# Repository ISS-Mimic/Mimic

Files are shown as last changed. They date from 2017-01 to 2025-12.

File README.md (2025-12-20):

<!-- =========================================================
  ISS Mimic  •  Re-create the ISS attitude & telemetry in real-time
  ========================================================= -->

<p align="center">
  ISS Mimic logo
</p>

<p align="center">
  
  
  
  
</p>

> **ISS Mimic** is an open-source mash-up of hardware + software that **mirrors the International Space Station’s solar-array and radiator motion** in real time.  
> Runs on Raspberry Pi • 12 motors drive a 3-D printed ISS • Live telemetry visualizer

---

ISS Mimic is a 3D printed model of the International Space Station that connects to the actual live data from the real ISS to control a model that rotates solar panels and radiators to match the real one in real time. The goal of this project is to connect people with the ISS. There are three different mimic models: Mimic, Mini Mimic, and Edu Mimic. These models are designed for teachers, students, museums, hobbyists, and anyone who wants to learn more about the ISS. 

Join the discussion, help out, ask for help, chat about the ISS here: [Mimic Discord](https://discord.gg/zPKyE6hBSe)



<details>
<summary>Table of Contents</summary>

- [Features](#features)
- [Quick Start (Raspberry Pi)](#quick-start-raspberry-pi)
- [Project Architecture](#project-architecture)
- [Build Your Own Model](#build-your-own-model)
- [Screenshots](#screenshots)
- [Contributing](#contributing)
- [Roadmap](#roadmap)
- [License](#license)
</details>

---

### Features
- **Live telemetry pull** from NASA’s Lightstreamer endpoint – no scraping needed  
- **Interactive dashboards** (more capable than the original ISSLive site)  
- **Real-time kinematics**: 12-axis motion matches α- and β-gimbal joint angles  
- **Modular design**: Separate Pi (telemetry & UI) ↔ Arduino (motor control)  
- **Low- / High-fidelity STLs** you can print today  

### Quick Start (Raspberry Pi)
```bash
# 1. Clone & install deps
  git clone --depth 1 https://github.com/ISS-Mimic/Mimic.git/ 
  cd ~/Mimic
  python setup.py

# 2. Run the Mimic GUI dashboard
  cd ~/Mimic/Pi/
  python GUI.py
```
Full software guide: [Wiki » Software Setup Instructions](https://github.com/ISS-Mimic/Mimic/wiki/Build-Instruction%3A-Mimic-Software-Setup-Instructions).

### Telemetry
Telemetry is data remotely collected from the ISS and transmitted to the ISS Mission Control Centers for monitoring the operational status of ISS systems. 

In 2011 some incredible JSC employees released a subset of the 100,000+ ISS telemetry items to the public under the ISSlive! project and an associated website.
Sadly, that website is no longer running, but they opened the door for dozens of projects to follow in their footsteps. 

NASA contracted the wonderful folks at [Lightstreamer](https://lightstreamer.com/) to provide this subset of ISS telemetry out to the public and that is the source of all the public telemetry projects today. 

We have made three telemetry pages to show off all of the public data (as well as our Pi application screens).

A filterable table here: https://iss-mimic.github.io/Mimic/ (and in Russian: https://iss-mimic.github.io/Mimic/index_ru.html)
and a great dashboard here: https://iss-mimic.github.io/Mimic/dashboard.html

### Project Architecture
```text
┌──────────┐              ┌──────────────┐                ┌──────────────┐                 ┌──────────┐
│ NASA LS  │────────────▶│ Raspberry Pi │───────────────▶│  Arduino(s)  │───────────────▶│  Motors  │
└──────────┘  telemetry   └──────────────┘  joint angles  └──────────────┘  motor commands └──────────┘
```
*Pi side* (Python + Kivy) shows telemetry dashboards and forwards joint targets.  
*Arduino side* (C++) drives stepper/servo motors in the 3-D-printed truss.

### Build Your Own Model
| Fidelity | STL pack | Status |
|---|---|---|
| Low | [`/3D_Printing`](3D_Printing) | ✔ Complete |
| High | `/3D_Printing/high_fidelity` | In progress – contributors welcome! |

Mechanical details, BOM, and wiring live in the **[Hardware Wiki section](https://github.com/ISS-Mimic/Mimic/wiki/Hardware)**.

### Screenshots
<p align="center">
  Mimic1
  Mimic2
  Mimic3
  <br>
  Mimic4
  Mimic5
  Mimic6
  <br>
  Mimic7
  Mimic8
  Mimic9
</p>

### Contributing
Start by opening an issue to suggest am improvement or bug or by chatting on **[Discord](https://discord.gg/zPKyE6hBSe)**.  
Coding guidelines:
1. Follow **PEP 8** and keep GUI layout in **`.kv` files** (Kivy best practice).  
2. Fix all our mistakes. 

Other help:
-Feel free to suggest ideas! Best place to talk is out discord, or feel free to publish an issue

### Roadmap
- [ ] Finish high-fidelity CAD & release STEP source
- [ ] Complete build guide
- [ ] Finish Kivy telemetry screens  

### License
This project is licensed under the MIT License – see [`LICENSE`](LICENSE) for details.

<details>
<summary>The code is ugly and awful but it works *mostly* (click to vent)</summary>

We’re hardware engineers moonlighting as coders. Expect caffeine-driven hacks and the occasional refactor fiasco. Contributions and constructive feedback are *super* welcome!
</details>

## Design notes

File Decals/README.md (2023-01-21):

# Vinyl cut Recommendation 

|  **Sub-Assembly / Module Name** | **STL Name & Link** | **Qty** | **Color** | **Comments** | **Approx  Time [h:mm]** | **_** | **_** |
| ---- | --- | --- | --- | --- | --- | --- | --- |
| Solar Array | [SAW_svg_working.svg ***](https://github.com/ISS-Mimic/Mimic/blob/main/Decals/SAWvinylFinal.svg) | 4 | Holographic Chrome Gold vinyl | [ To download .svg file, click on 'Raw' then 'right click' to save image.  Click here to open vinyl cut instructions.  Be sure to click the " **More Pages**" button in Github to see all instructions on using Cricut](https://github.com/ISS-Mimic/Mimic/blob/main/Decals/Vinyl_Cutting_Instructions_using_Cricut_.pdf) | 5:00 |  |  |
| Solar Array Back | [SAW_svg_working_BACK.svg ]() | 16 | Matte Metallic Champagne Gold vinyl |  | 0:10 |  |  |
| Solar Array Blue | [SAW_svg_working_BACK.svg ]() | 16 | Blue vinyl |  | 0:10 |  |  |
| IPA Roll Out Solar Arrays | [iROSA_SAWvinylFinal.svg ***](https://github.com/ISS-Mimic/Mimic/blob/main/Decals/iROSA_SAWvinylFinal.svg) | 2 | Holographic Chrome Gold vinyl |  | 2:00 |  |  |

*** Note: to download .svg file:
    >> copy all raw content
    >> paste into notepad
    >> save file with .svg extention ***

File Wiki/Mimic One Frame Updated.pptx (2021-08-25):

## Mimic One Frame Build Instruction (Example)

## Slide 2

FWD

2020 Vertical Supports (4)

Extruded 2040 Base

2020 Frame Supports (6)

Support Rods with Base (3)

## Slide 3

Step 1: Attach Frame Supports to 2040 Base (6 places)
2 small L-brackets each support, 2 Button Hex Screws each small L-bracket

Measurements are from centerline to centerline

2020 Frame Supports (6)

Frame Supports attached to 2040 Base by 2 small L-brackets using Button Hex Screws

Extruded 2040 Base

~610mm

~610mm

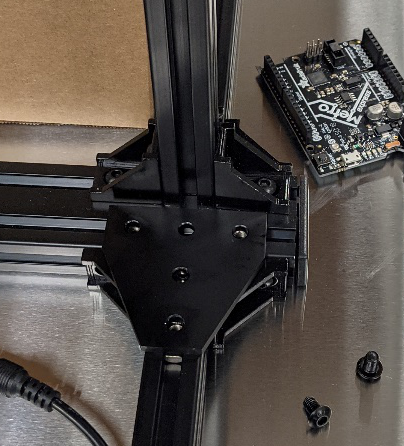
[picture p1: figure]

L-brackets

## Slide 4

Step 1a: Cut Rubber Strips for Frame Supports (6 places) and 2040 Base (both grooves)
Install Rubber Strips in the underside grooves of Frame Supports and 2040 Base.

The Rubber Strip provides friction with the table and to fill the space between the table and the Rubber Feet on the end of the Frame Supports.

2020 Frame Supports (6)

Extruded 2040 Base (both grooves)

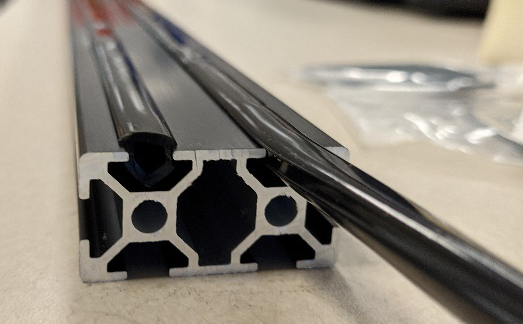
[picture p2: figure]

2040 Base shown upside down

Underside Groove

Rubber Strip

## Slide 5

Step 2: Install T-Plates on end Frame Supports in the rear groove of the 2040 (2 places)
1 T-plate per end Frame Support, 5 Button Hex Screws and T-nuts on each T-plate

2020 Frame Supports (6)

Frame Supports attached to 2040 Base by 2 small L-brackets and 1 T-plate using Button Hex Screws

Extruded 2040 Base

T-plate

L-brackets

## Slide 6

Step 3: Install T-Plates on center Frame Supports – one in forward groove, one in rear groove (2 places)
1 T-plate per center Frame Support, 5 Button Hex Screws and T-nuts on each T-plate

FWD

2020 Frame Supports (6)

Extruded 2040 Base

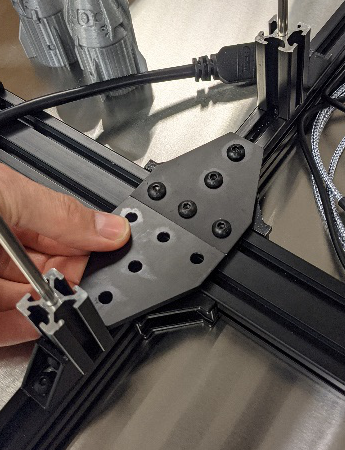
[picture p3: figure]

T-plates

Forward Groove in 2040

Rear Groove in 2040

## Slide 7

Vertical Supports (without T-plates) attached to forward groove with 2 small
L-brackets using
Button Hex screws

2020 Vertical Supports (4)

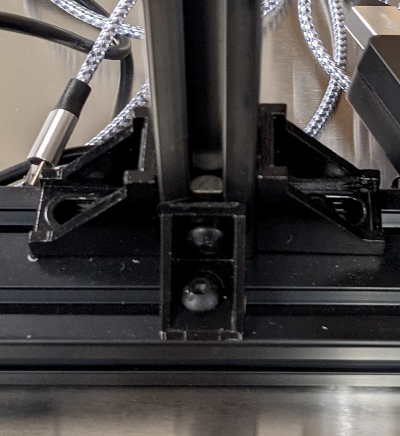
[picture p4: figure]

L-brackets

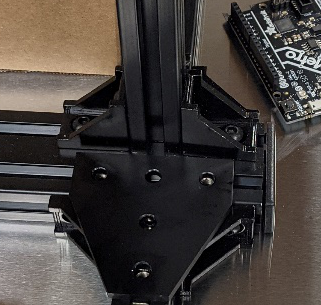
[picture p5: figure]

L-brackets

Vertical Supports attached to forward groove on 2040 Base by 2 small L-brackets using Button Hex Screws

Measurements are centerline to centerline.
Need to update: outside dimensions should be the same.

FWD

446mm

433mm

347mm

Extruded 2040 Base

Step 4: Attach Vertical Supports to forward groove in 2040 Base (4 places)
2 small L-brackets each support, 2 Button Hex Screws each small L-bracket

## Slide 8

Vertical Supports (without T-plates) attached to forward groove with 2 small
L-brackets and 1
L-bracket anchored in rear groove

2020 Vertical Supports (4)

Step 5: Add 1 large L-bracket anchored in rear groove in 2040 Base on center supports(2 places)
1 large L-bracket each support, 2 Button Hex Screws each small L-bracket

FWD

Extruded 2040 Base

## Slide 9

Step 6: Support Rod Bases on center Frame Supports (3 places)
1 large L-bracket per Support Rod Base, 2 Button Hex Screws each L-bracket

2020 Frame Supports (6)

160mm

243mm

Extruded 2040 Base

L-brackets

Vertical 2020 is flush
with end of the horizontal 2020

Support Rods with Base (3)

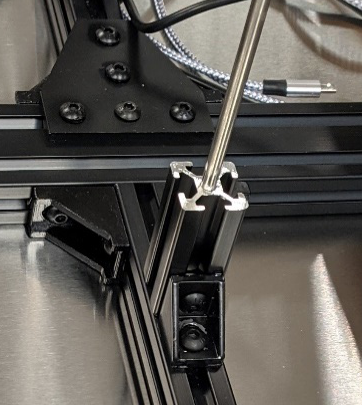
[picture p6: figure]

Support Rod Base attached to 2020 Frame Support by 1 large
L-bracket using Button Hex Screws

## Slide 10

Step 7: Install Rubber Feet on Support Rod Bases (3 places)
Rubber Feet finish off ends of extruded Support Rod Bases and provide additional support with rods

Note, a cut will need to be made or a small hole drilled to allow Support Rod to pass through – hole must be smaller than rod to provide friction for extra stability

2020 Frame Supports (6)

Extruded 2040 Base

Add new photo with rubber

Rubber Feet on Support Rod Base

Support Rods with Base (3)

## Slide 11

Step 8: Insert Support Rods in Support Rod Bases (3 places)
Support Rod will drop down into groove of Frame Support

2020 Frame Supports (6)

Extruded 2040 Base

Add new photo with rubber

Support Rod inserted through Rubber Feet into Support Rod Base

Support Rods with Base (3)

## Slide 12

Step 9: Install Rubber Feet on Frame Supports (6 places)
Rubber Feet finish off ends of Frame Supports and provide friction with table

2020 Frame Supports (6)

Extruded 2040 Base

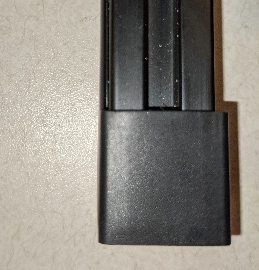
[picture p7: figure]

Support Rods with Base (3)

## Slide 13

Step 10: Install End Caps on 2040 Base ends (2 places)
End Caps finish off ends of 2040 Base

Extruded 2040 Base

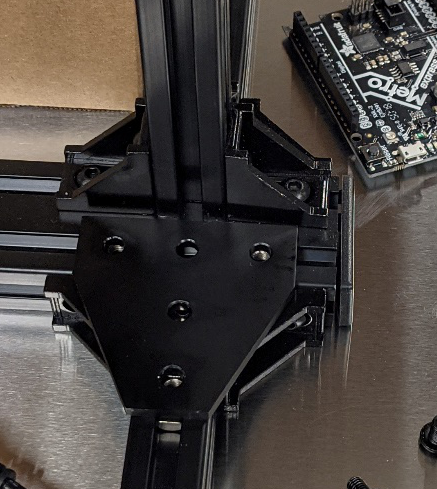
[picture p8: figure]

End Cap (2) inserted into end of 2040 Base

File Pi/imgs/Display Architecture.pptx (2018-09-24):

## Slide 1

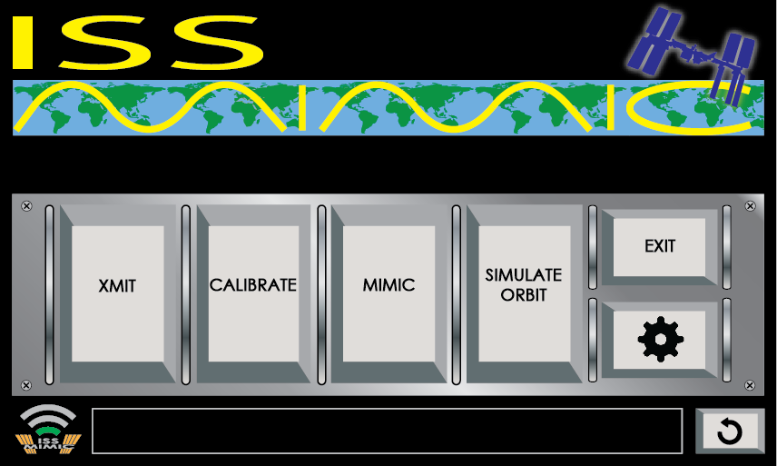
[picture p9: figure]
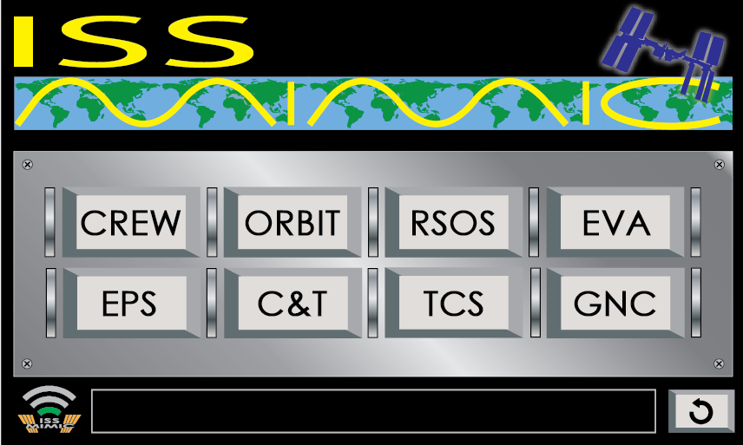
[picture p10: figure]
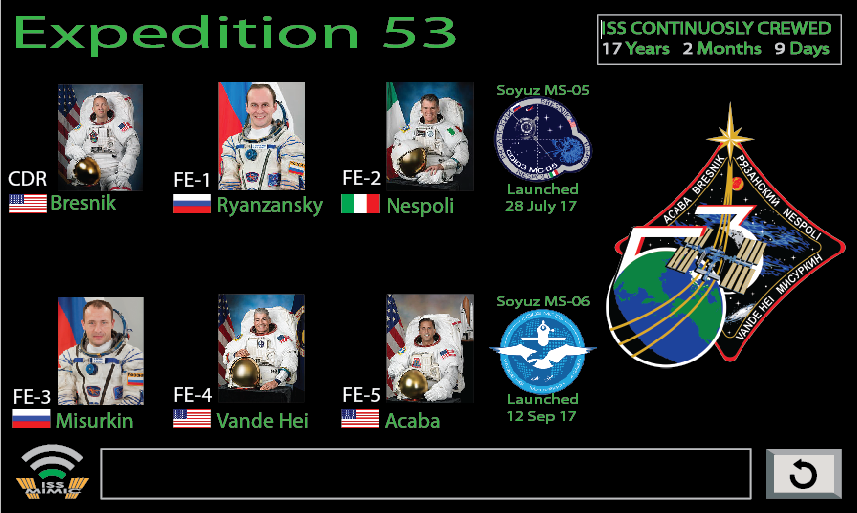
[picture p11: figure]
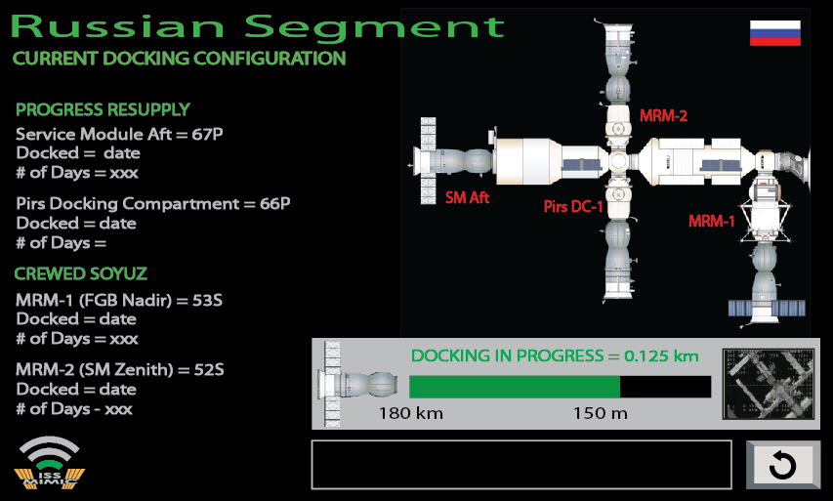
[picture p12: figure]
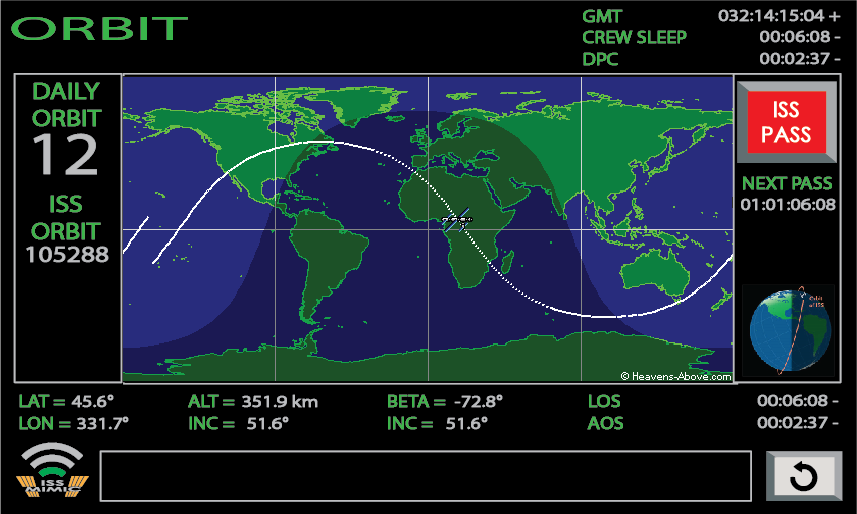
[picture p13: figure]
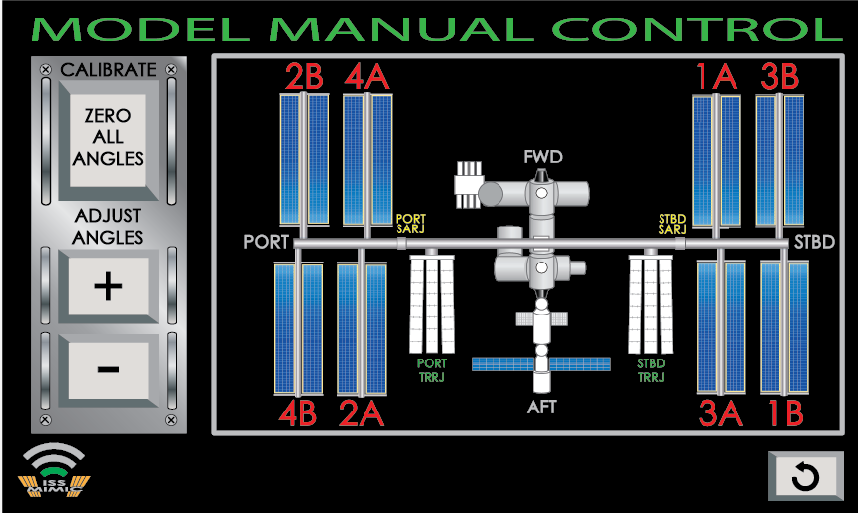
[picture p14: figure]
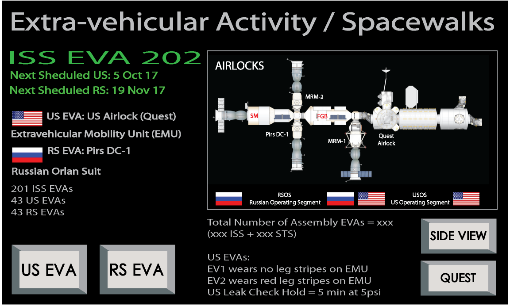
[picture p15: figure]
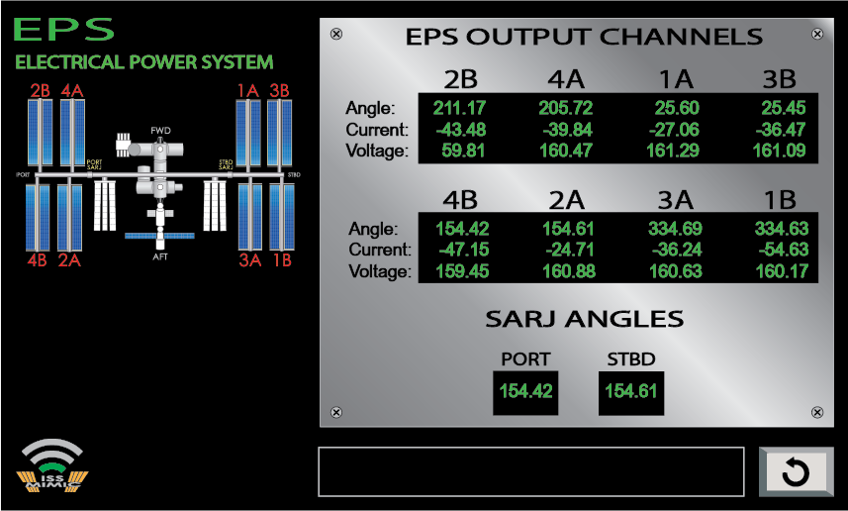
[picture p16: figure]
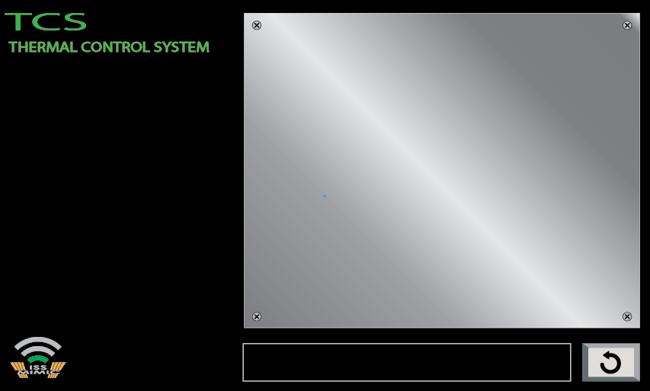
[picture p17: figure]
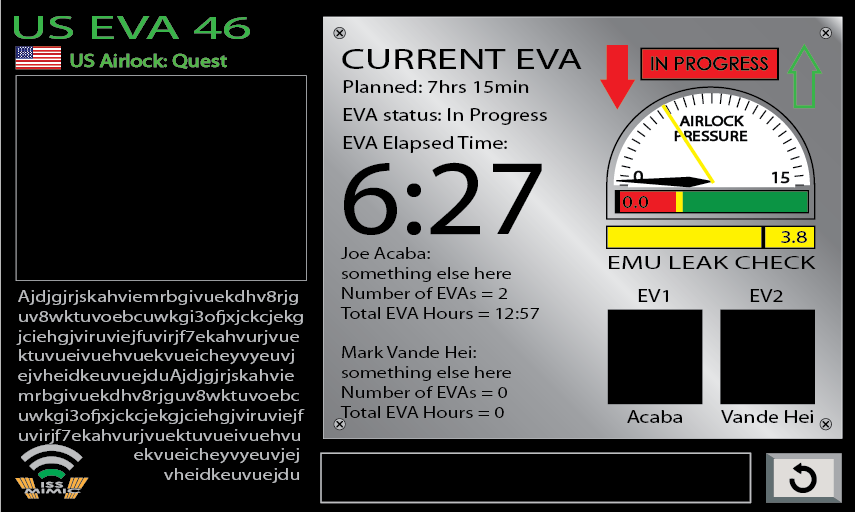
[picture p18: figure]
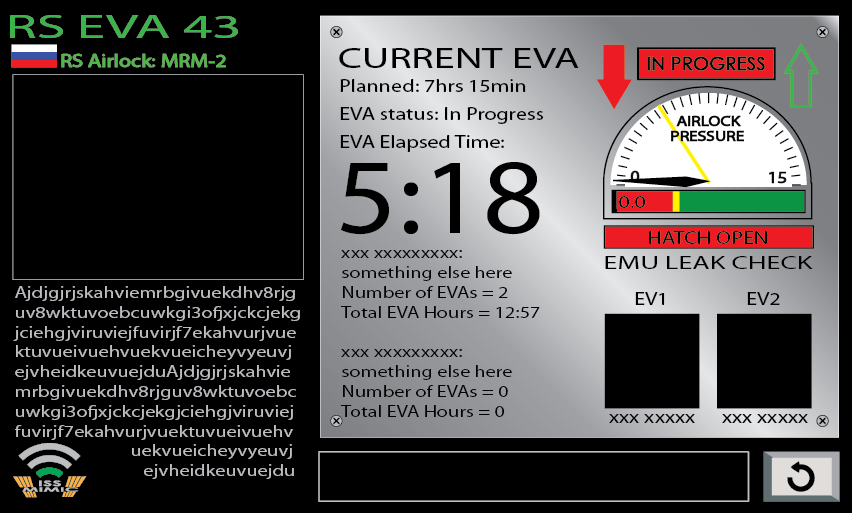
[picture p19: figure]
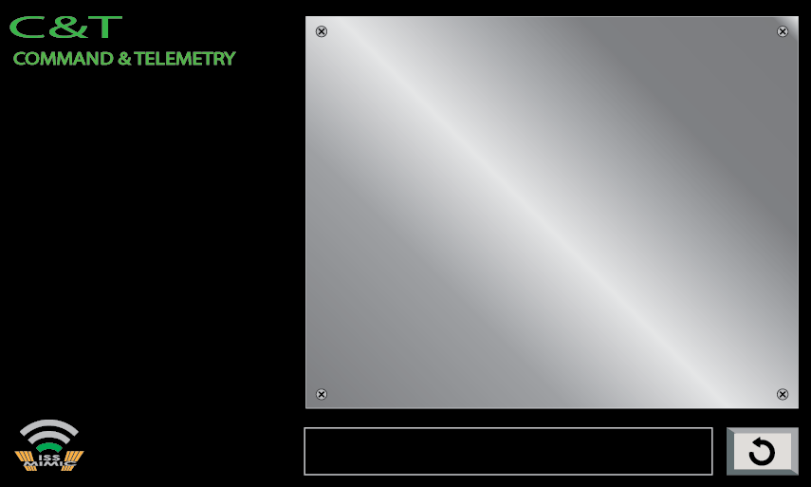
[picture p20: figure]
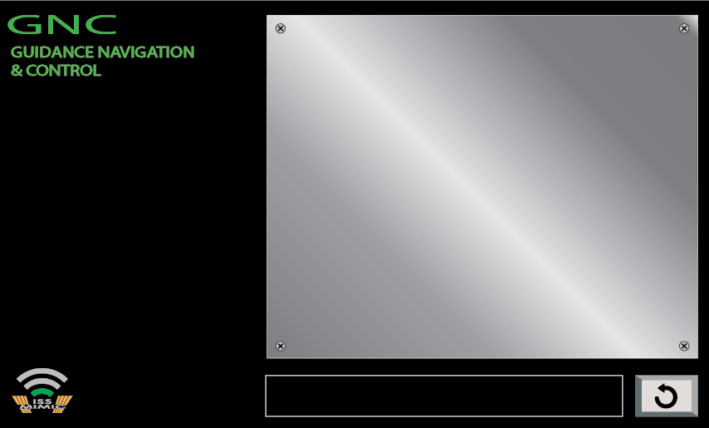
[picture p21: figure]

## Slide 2

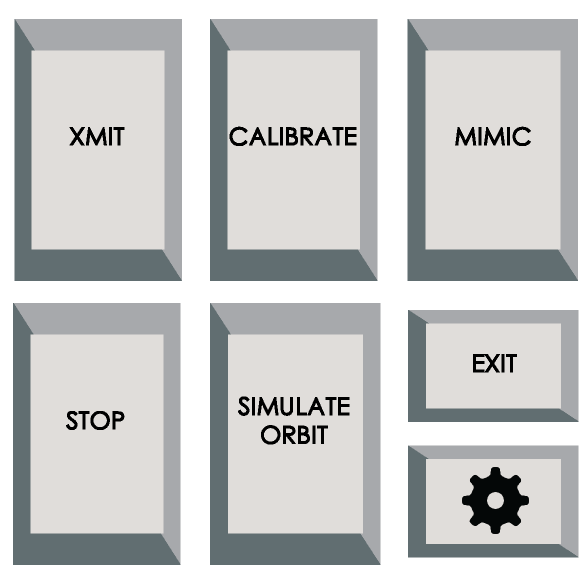
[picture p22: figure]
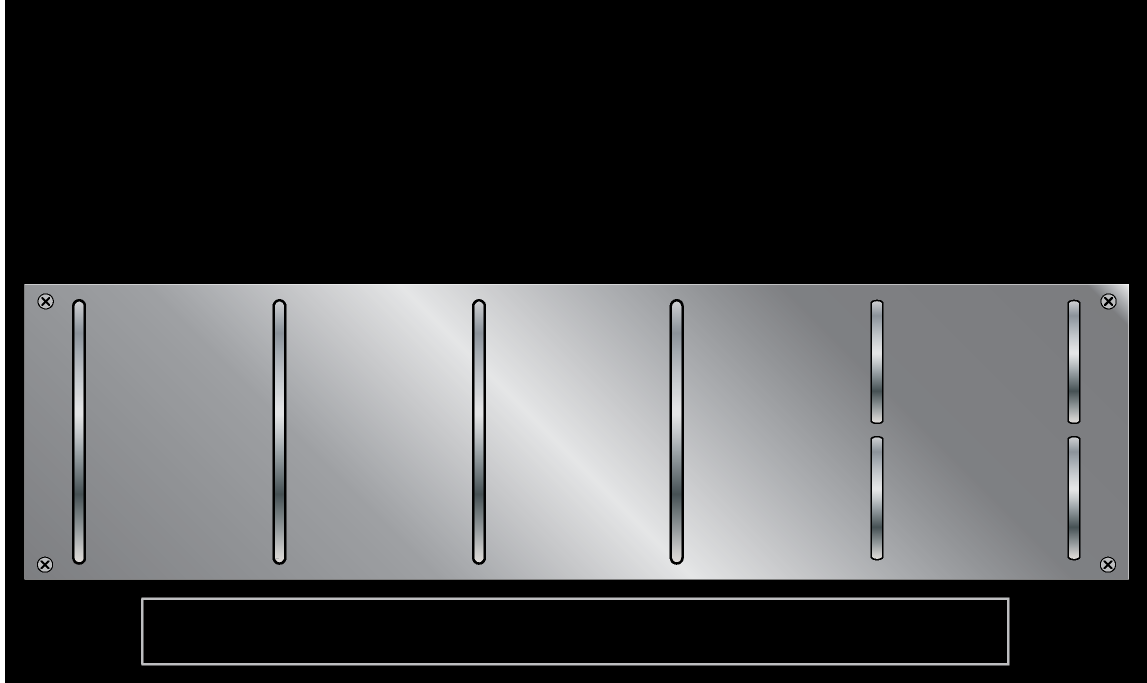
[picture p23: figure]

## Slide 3

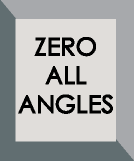
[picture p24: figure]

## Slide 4


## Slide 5


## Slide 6

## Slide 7

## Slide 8

View Buttons are static – choose from Side View or Quest View (don’t remember why I did that)


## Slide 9

Maybe if tweet is more than 220 characters, you truncate it or show 150 and spit out a link like it does on my phone

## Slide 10

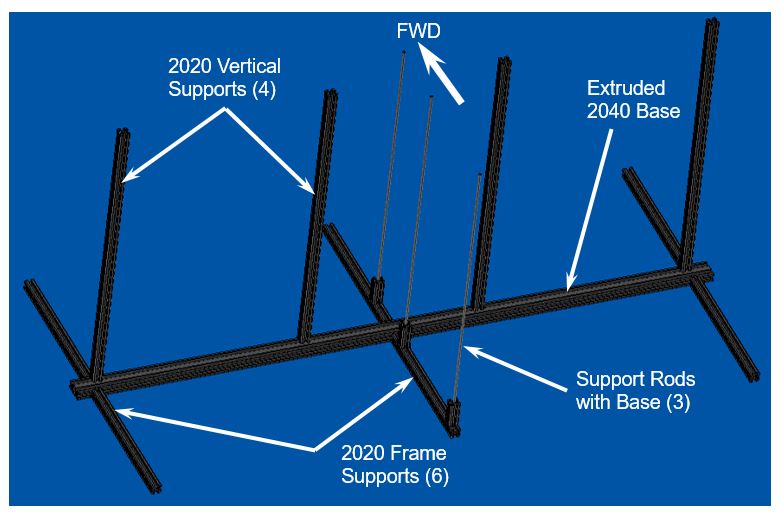
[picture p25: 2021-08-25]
Wiki/Images/FrameOverview.JPG

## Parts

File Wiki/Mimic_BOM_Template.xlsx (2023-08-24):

 |  |  |  |  |  |  |  | output string - copy everything below in this column for the markdown file |  |  |  |  |  |  |  |  | concats
 |  |  |  |  |  |  |  | ### Raspberry Pi / Mimic Control Unit
 |  |  |  |  |  |  |  | | **Part** | **Quantity** | **Cost Per Unit** | **Total Cost** | **URL** | **Notes** | **Image**
Part | Quantity | Cost Per Unit | Total Cost | Part URL Name | Part URL | Notes | Image URL | | --- | :--: | :--: | :--: | --- | --- | ---
4GB Raspberry Pi 4 | 1 | $67.79 | $67.79 | Amazon | https://www.amazon.com/dp/B07TC2BK1X | Might work with the 1GB/2GB versions but not guaranteed | https://images-na.ssl-images-amazon.com/images/I/71RJj8SmQGL._SL1500_.jpg | | 4GB Raspberry Pi 4 | 1 | $67.79 | $67.79 | [Amazon](https://www.amazon.com/dp/B07TC2BK1X) | Might work with the 1GB/2GB versions but not guaranteed | <img src="https://images-na.ssl-images-amazon.com/images/I/71RJj8SmQGL._SL1500_.jpg" width="200">
Power Supply | 1 | $9.99 | $9.99 | Amazon | https://www.amazon.com/gp/product/B097P2NLVH/ | Need at least 2.4 amp power supply | https://m.media-amazon.com/images/I/610tc+KJ17S._AC_SL1500_.jpg | | Power Supply | 1 | $9.99 | $9.99 | [Amazon](https://www.amazon.com/gp/product/B097P2NLVH/) | Need at least 2.4 amp power supply | <img src="https://m.media-amazon.com/images/I/610tc+KJ17S._AC_SL1500_.jpg" width="200">
MicroSD Card | 1 | $8.98 | $8.98 | Amazon | https://www.amazon.com/SanDisk-Ultra-microSDXC-Memory-Adapter/dp/B073JWXGNT | Recommend 32GB, you'll also need a microSD card reader | https://images-na.ssl-images-amazon.com/images/I/81ClkOh2gpL._SL1500_.jpg | | MicroSD Card | 1 | $8.98 | $8.98 | [Amazon](https://www.amazon.com/SanDisk-Ultra-microSDXC-Memory-Adapter/dp/B073JWXGNT) | Recommend 32GB, you'll also need a microSD card reader | <img src="https://images-na.ssl-images-amazon.com/images/I/81ClkOh2gpL._SL1500_.jpg" width="200">
Raspberry Pi Official Touchscreen | 1 | $92.81 | $92.81 | Amazon | https://www.amazon.com/Raspberry-Pi-7-Touchscreen-Display/dp/B0153R2A9I/ | Possible to use other screens but the program was designed for this one | https://images-na.ssl-images-amazon.com/images/I/51Fju0ie9sL._SL1000_.jpg | | Raspberry Pi Official Touchscreen | 1 | $92.81 | $92.81 | [Amazon](https://www.amazon.com/Raspberry-Pi-7-Touchscreen-Display/dp/B0153R2A9I/) | Possible to use other screens but the program was designed for this one | <img src="https://images-na.ssl-images-amazon.com/images/I/51Fju0ie9sL._SL1000_.jpg" width="200">
Raspberry Pi/Touchscreen Case (optional) | 1 | $29.99 | $29.99 | Amazon | https://www.amazon.com/SmartiPi-Touch-Official-Raspberry-Touchscreen/dp/B07WXK38YM/ | This is the best Raspi Case but again not strictly required | https://images-na.ssl-images-amazon.com/images/I/71P7ThIhIRL._SL1500_.jpg | | Raspberry Pi/Touchscreen Case (optional) | 1 | $29.99 | $29.99 | [Amazon](https://www.amazon.com/SmartiPi-Touch-Official-Raspberry-Touchscreen/dp/B07WXK38YM/) | This is the best Raspi Case but again not strictly required | <img src="https://images-na.ssl-images-amazon.com/images/I/71P7ThIhIRL._SL1500_.jpg" width="200">
4-Port Powered USB Hub | 1 | $19.99 | $19.99 | Amazon | https://www.amazon.com/gp/product/B00TPMEOYM/ | Any powered hub should work, but this is the one we for which we've designed a mount | https://m.media-amazon.com/images/I/71fOD0-BRQL._AC_SL1500_.jpg | | 4-Port Powered USB Hub | 1 | $19.99 | $19.99 | [Amazon](https://www.amazon.com/gp/product/B00TPMEOYM/) | Any powered hub should work, but this is the one we for which we've designed a mount | <img src="https://m.media-amazon.com/images/I/71fOD0-BRQL._AC_SL1500_.jpg" width="200">
USB-A to USB-Micro B data cables | 1 | $11.99 | $11.99 | Amazon | https://www.amazon.com/gp/product/B011KLFERG/ | Four cables required. You can use old phone cables, but make sure they support data transfer, not just charging | https://m.media-amazon.com/images/I/81z7vkDJTdL._AC_SL1500_.jpg | | USB-A to USB-Micro B data cables | 1 | $11.99 | $11.99 | [Amazon](https://www.amazon.com/gp/product/B011KLFERG/) | Four cables required. You can use old phone cables, but make sure they support data transfer, not just charging | <img src="https://m.media-amazon.com/images/I/81z7vkDJTdL._AC_SL1500_.jpg" width="200">
Mini Wireless Keyboard + Mouse (optional) | 1 | $29.95 | $29.95 | Amazon | https://www.amazon.com/gp/product/B011KPIZ9G/ | Use whatever mouse + keyboard you like, we like how this is a mouse and keyboard, portable and only uses one USB port | https://images-na.ssl-images-amazon.com/images/I/41YUr5YjuFL._AC_.jpg | | Mini Wireless Keyboard + Mouse (optional) | 1 | $29.95 | $29.95 | [Amazon](https://www.amazon.com/gp/product/B011KPIZ9G/) | Use whatever mouse + keyboard you like, we like how this is a mouse and keyboard, portable and only uses one USB port | <img src="https://images-na.ssl-images-amazon.com/images/I/41YUr5YjuFL._AC_.jpg" width="200">
USB Battery Pack (optional) | 1 | $49.95 | $49.95 | Amazon | https://www.amazon.com/Anker-PowerCore-Technology-High-Capacity-Compatible/dp/B07S829LBX/ | If you want to have a portable power option for the Raspberry Pi Station, this is a good option | https://images-na.ssl-images-amazon.com/images/I/71PYhWFaWEL._AC_SL1500_.jpg | | USB Battery Pack (optional) | 1 | $49.95 | $49.95 | [Amazon](https://www.amazon.com/Anker-PowerCore-Technology-High-Capacity-Compatible/dp/B07S829LBX/) | If you want to have a portable power option for the Raspberry Pi Station, this is a good option | <img src="https://images-na.ssl-images-amazon.com/images/I/71PYhWFaWEL._AC_SL1500_.jpg" width="200">
 |  |  |  |  |  |  |  | | **Subtotal** | **Subtotal + Keyboard & Battery**
 |  |  |  |  |  |  |  | | :---: | :---:
 |  | $241.54 | $321.44 |  |  |  |  | | $241.54 | $321.44
 |  |  |  |  |  |  |  | ### Essential Parts
 |  |  |  |  |  |  |  | | **Part** | **Quantity** | **Cost Per Unit** | **Total Cost** | **URL** | **Notes** | **Image**
Part | Quantity | Cost Per Unit | Total Cost | Part URL Name | Part URL | Notes | Image URL | | --- | :--: | :--: | :--: | --- | --- | ---
175 RPM Micro Gear Motor w/Encoder | 10 | $19.99 | $199.90 | Amazon | https://www.amazon.com/175-RPM-Micro-Gearmotor-Encoder/dp/B0195C9GSU | Motor for SARJs + BGAs | https://github.com/ISS-Mimic/Mimic/blob/main/Wiki/Images/DCmotor.png | | 175 RPM Micro Gear Motor w/Encoder | 10 | $19.99 | $199.9 | [Amazon](https://www.amazon.com/175-RPM-Micro-Gearmotor-Encoder/dp/B0195C9GSU) | Motor for SARJs + BGAs | <img src="https://github.com/ISS-Mimic/Mimic/blob/main/Wiki/Images/DCmotor.png" width="200">
Motor mount screws | 1 | $9.54 | $9.54 | McMasterCarr | https://www.mcmaster.com/92010A779/ | Mounts motors in place. M1.6x4mm flat head hex screw (100 pack). Total of 20 screws required. | https://github.com/ISS-Mimic/Mimic/blob/main/Wiki/Images/mmc_screw.png | | Motor mount screws | 1 | $9.54 | $9.54 | [McMasterCarr](https://www.mcmaster.com/92010A779/) | Mounts motors in place. M1.6x4mm flat head hex screw (100 pack). Total of 20 screws required. | <img src="https://github.com/ISS-Mimic/Mimic/blob/main/Wiki/Images/mmc_screw.png" width="200">
Couplers to Mount Solar Arrays on the motors | 1 | $10.99 | $10.99 | Amazon | https://www.amazon.com/Befenybay-Connector-Copper-Flexible-Coupling/dp/B07VFFJBVH/ | (8 Pcs) 3mm to 3mm Brass Connector Copper | https://images-na.ssl-images-amazon.com/images/I/71Gfh5ie8ML._AC_SX679_.jpg | | Couplers to Mount Solar Arrays on the motors | 1 | $10.99 | $10.99 | [Amazon](https://www.amazon.com/Befenybay-Connector-Copper-Flexible-Coupling/dp/B07VFFJBVH/) | (8 Pcs) 3mm to 3mm Brass Connector Copper | <img src="https://images-na.ssl-images-amazon.com/images/I/71Gfh5ie8ML._AC_SX679_.jpg" width="200">
Replacement Set Screws for Solar Array Couplers | 1 | $3.50 | $3.50 | McMaster | https://www.mcmaster.com/92605A100/ | M3 x 6mm Long Stainless Steel Flat-Tip Set Screw (Pkg of 25) | https://github.com/ISS-Mimic/Mimic/blob/main/Wiki/Images/mmc_setscrew.png | | Replacement Set Screws for Solar Array Couplers | 1 | $3.5 | $3.5 | [McMaster](https://www.mcmaster.com/92605A100/) | M3 x 6mm Long Stainless Steel Flat-Tip Set Screw (Pkg of 25) | <img src="https://github.com/ISS-Mimic/Mimic/blob/main/Wiki/Images/mmc_setscrew.png" width="200">
Pinion Gear to work with printed SARJ Ring | 2 | $9.70 | $19.40 | Amazon | https://www.amazon.com/Traxxas-3942X-Hardened-12-Tooth-Pinion/dp/B078KFCN72 | Traxxas 3942X 12-T Pinion Gear, 32P | https://m.media-amazon.com/images/I/41lWRhK7rWS._AC_SL1400_.jpg | | Pinion Gear to work with printed SARJ Ring | 2 | $9.7 | $19.4 | [Amazon](https://www.amazon.com/Traxxas-3942X-Hardened-12-Tooth-Pinion/dp/B078KFCN72) | Traxxas 3942X 12-T Pinion Gear, 32P | <img src="https://m.media-amazon.com/images/I/41lWRhK7rWS._AC_SL1400_.jpg" width="200">
Slip Ring | 4 | $21.00 | $84.00 | Amazon | https://www.amazon.com/GeeBat-Capsule-Electrical-CIRCUITSx2A-equipment/dp/B01N63E1N3 | Slip Ring - 12 Wires with Flange | https://images-na.ssl-images-amazon.com/images/I/71P8F3tKd3L._AC_SX679_.jpg | | Slip Ring | 4 | $21 | $84 | [Amazon](https://www.amazon.com/GeeBat-Capsule-Electrical-CIRCUITSx2A-equipment/dp/B01N63E1N3) | Slip Ring - 12 Wires with Flange | <img src="https://images-na.ssl-images-amazon.com/images/I/71P8F3tKd3L._AC_SX679_.jpg" width="200">
Motor Driver Shield | 3 | $23.99 | $71.97 | Amazon | https://www.amazon.com/gp/product/B073SP76MC/ | HiLetgo TB6612 Mosfet for Arduino Motor Shield | https://m.media-amazon.com/images/I/61w0lRDnX5L._AC_SL1010_.jpg | | Motor Driver Shield | 3 | $23.99 | $71.97 | [Amazon](https://www.amazon.com/gp/product/B073SP76MC/) | HiLetgo TB6612 Mosfet for Arduino Motor Shield | <img src="https://m.media-amazon.com/images/I/61w0lRDnX5L._AC_SL1010_.jpg" width="200">
Adafruit Metro M0 | 4 | $36.95 | $147.80 | Amazon | https://www.amazon.com/Adafruit-3505-Metro-Express-CircuitPython/dp/B071P145RG/ | Adafruit (PID 3505 Metro M0 Express - Designed for CircuitPython - ATSAMD21G18 | https://images-na.ssl-images-amazon.com/images/I/811K-LHnsoL._AC_SL1200_.jpg | | Adafruit Metro M0 | 4 | $36.95 | $147.8 | [Amazon](https://www.amazon.com/Adafruit-3505-Metro-Express-CircuitPython/dp/B071P145RG/) | Adafruit (PID 3505 Metro M0 Express - Designed for CircuitPython - ATSAMD21G18 | <img src="https://images-na.ssl-images-amazon.com/images/I/811K-LHnsoL._AC_SL1200_.jpg" width="200">
Servo Motors for Radiators | 1 | $9.99 | $9.99 | Amazon | https://www.amazon.com/Micro-Servos-Helicopter-Airplane-Controls/dp/B07MLR1498/ | TowerPro SG90 Servo (2 required, 4 in this pack) | https://images-na.ssl-images-amazon.com/images/I/61EX8cfTXRL._AC_SL1200_.jpg | | Servo Motors for Radiators | 1 | $9.99 | $9.99 | [Amazon](https://www.amazon.com/Micro-Servos-Helicopter-Airplane-Controls/dp/B07MLR1498/) | TowerPro SG90 Servo (2 required, 4 in this pack) | <img src="https://images-na.ssl-images-amazon.com/images/I/61EX8cfTXRL._AC_SL1200_.jpg" width="200">
Jumper Wires for Motor and Mimic Shields | 1 | $6.98 | $6.98 | Amazon | https://www.amazon.com/gp/product/B01EV70C78/ (https://smile.amazon.com/gp/product/B01EV70C78/) | 20cm Assorted Breadboard Jumper Wires | https://m.media-amazon.com/images/I/81lyrrBqMIL._AC_SL1500_.jpg | | Jumper Wires for Motor and Mimic Shields | 1 | $6.98 | $6.98 | [Amazon](https://www.amazon.com/gp/product/B01EV70C78/) | 20cm Assorted Breadboard Jumper Wires | <img src="https://m.media-amazon.com/images/I/81lyrrBqMIL._AC_SL1500_.jpg" width="200">
12V/5A Power Supply for Motors | 1 | $12.99 | $12.99 | Amazon | https://www.amazon.com/gp/product/B01461MOGQ (https://smile.amazon.com/gp/product/B01461MOGQ) | LEDMO Power Supply | https://m.media-amazon.com/images/I/51a0PcZlVkL._AC_.jpg | | 12V/5A Power Supply for Motors | 1 | $12.99 | $12.99 | [Amazon](https://www.amazon.com/gp/product/B01461MOGQ) | LEDMO Power Supply | <img src="https://m.media-amazon.com/images/I/51a0PcZlVkL._AC_.jpg" width="200">
Inline On/Off Switch (Optional) | 1 | $9.99 | $9.99 | Amazon | https://www.amazon.com/AWADUO-Extension-Adapter-Connector-Security/dp/B0B4638FG | JEEUE 12V Power DC Male to Female Cable with On/Off Switch | https://m.media-amazon.com/images/I/51istd+aMsL._SL1000_.jpg | | Inline On/Off Switch (Optional) | 1 | $9.99 | $9.99 | [Amazon](https://www.amazon.com/AWADUO-Extension-Adapter-Connector-Security/dp/B0B4638FG) | JEEUE 12V Power DC Male to Female Cable with On/Off Switch | <img src="https://m.media-amazon.com/images/I/51istd+aMsL._SL1000_.jpg" width="200">
DC Power Splitter Cable | 1 | $8.99 | $8.99 | Amazon | https://www.amazon.com/gp/product/B06Y5G3CMJ (https://smile.amazon.com/gp/product/B06Y5G3CMJ) | DZYDZR 3pcs 5.5mm x 2.1mm Y Splitter Cable 1 Female to 3 Male Splitter | https://m.media-amazon.com/images/I/61rz64AJ-KL._AC_SL1000_.jpg | | DC Power Splitter Cable | 1 | $8.99 | $8.99 | [Amazon](https://www.amazon.com/gp/product/B06Y5G3CMJ) | DZYDZR 3pcs 5.5mm x 2.1mm Y Splitter Cable 1 Female to 3 Male Splitter | <img src="https://m.media-amazon.com/images/I/61rz64AJ-KL._AC_SL1000_.jpg" width="200">
DC Power Plug Pigtail | 1 | $8.43 | $8.43 | Amazon | https://www.amazon.com/gp/product/B01M0EAR9N (https://smile.amazon.com/gp/product/B01M0EAR9N) | DC Power Plug Pigtail Cable (Female Power Plug Pigtail Cable / 19.68 inches/Pack of 10) | https://m.media-amazon.com/images/I/71WZivU7NpL._AC_SL1500_.jpg | | DC Power Plug Pigtail | 1 | $8.43 | $8.43 | [Amazon](https://www.amazon.com/gp/product/B01M0EAR9N) | DC Power Plug Pigtail Cable (Female Power Plug Pigtail Cable / 19.68 inches/Pack of 10) | <img src="https://m.media-amazon.com/images/I/71WZivU7NpL._AC_SL1500_.jpg" width="200">
Velcro Cable Ties (optional) | 1 | $6.99 | $6.99 | Amazon | https://www.amazon.com/gp/product/B00O9VKVFK (https://smile.amazon.com/gp/product/B00O9VKVFK) | Attmu 50 PCS Reusable Fastening Cable Ties | https://m.media-amazon.com/images/I/719z+1KonvL._AC_SL1500_.jpg | | Velcro Cable Ties (optional) | 1 | $6.99 | $6.99 | [Amazon](https://www.amazon.com/gp/product/B00O9VKVFK) | Attmu 50 PCS Reusable Fastening Cable Ties | <img src="https://m.media-amazon.com/images/I/719z+1KonvL._AC_SL1500_.jpg" width="200">
HDMI Cables (Generic) | 3 | $10.99 | $32.97 | Amazon | https://www.amazon.com/gp/product/B07LFN7CX6 | Any standard HDMI cable should work | https://m.media-amazon.com/images/I/610Y4RHIzRL._AC_SL1200_.jpg | | HDMI Cables (Generic) | 3 | $10.99 | $32.97 | [Amazon](https://www.amazon.com/gp/product/B07LFN7CX6) | Any standard HDMI cable should work | <img src="https://m.media-amazon.com/images/I/610Y4RHIzRL._AC_SL1200_.jpg" width="200">
 |  |  |  |  |  |  |  | | **Subtotal**
 |  |  |  |  |  |  |  | | :---:
 |  |  | $644.43 |  |  |  |  | | $644.43
 |  |  |  |  |  |  |  | ### Modelling (3D Printing/Module Connections/Aesthetics)
 |  |  |  |  |  |  |  | | **Part** | **Quantity** | **Cost Per Unit** | **Total Cost** | **URL** | **Notes** | **Image**
Part | Quantity | Cost Per Unit | Total Cost | Part URL Name | Part URL | Notes | Image URL | | --- | :--: | :--: | :--: | --- | --- | ---
3D Printer PLA Filament | 1 | $24.99 | $24.99 | Amazon | https://www.amazon.com/gp/product/B0B2NZZXLX | 3D Printer Filament, Polymaker White - be sure to get the proper diameter filament for your printer (feel free to use whatever filament) | https://m.media-amazon.com/images/I/71etInNZiSL._AC_SL1500_.jpg | | 3D Printer PLA Filament | 1 | $24.99 | $24.99 | [Amazon](https://www.amazon.com/gp/product/B0B2NZZXLX) | 3D Printer Filament, Polymaker White - be sure to get the proper diameter filament for your printer (feel free to use whatever filament) | <img src="https://m.media-amazon.com/images/I/71etInNZiSL._AC_SL1500_.jpg" width="200">
Ring Magnets for Module Connecting - lightweight | 60 | $0.52 | $31.20 | KJ Magnetics | https://www.kjmagnetics.com/proddetail.asp?prod=R841 | ½”OD x 1/4”ID x 1/16”thick ring magnets | https://www.kjmagnetics.com/prodimages2/1280/R841one.jpg | | Ring Magnets for Module Connecting - lightweight | 60 | $0.52 | $31.2 | [KJ Magnetics](https://www.kjmagnetics.com/proddetail.asp?prod=R841) | ½”OD x 1/4”ID x 1/16”thick ring magnets | <img src="https://www.kjmagnetics.com/prodimages2/1280/R841one.jpg" width="200">
Ring Magnets for Module Connecting - Heavyweight | 10 | $1.04 | $10.40 | KJ Magnetics | https://www.kjmagnetics.com/proddetail.asp?prod=R842-N52 | ½”OD x 1/4”ID x 1/8” thick ring magnets | https://www.kjmagnetics.com/prodimages2/1280/R842-N52one.jpg | | Ring Magnets for Module Connecting - Heavyweight | 10 | $1.04 | $10.4 | [KJ Magnetics](https://www.kjmagnetics.com/proddetail.asp?prod=R842-N52) | ½”OD x 1/4”ID x 1/8” thick ring magnets | <img src="https://www.kjmagnetics.com/prodimages2/1280/R842-N52one.jpg" width="200">
Cylinder Magnets for TBD | 2 | $1.40 | $2.80 | KJ Magnetics | https://www.kjmagnetics.com/proddetail.asp?prod=D12-N52 | 1/16”diam x 1/8” thick cylinder magnets | https://www.kjmagnetics.com/prodimages2/1280/D12-N52one.jpg | | Cylinder Magnets for TBD | 2 | $1.4 | $2.8 | [KJ Magnetics](https://www.kjmagnetics.com/proddetail.asp?prod=D12-N52) | 1/16”diam x 1/8” thick cylinder magnets | <img src="https://www.kjmagnetics.com/prodimages2/1280/D12-N52one.jpg" width="200">
Support Rods for Inboard Truss Segment | 2 | $2.54 | $5.08 | McMaster | https://www.mcmaster.com/98861A040/ | M3 Steel Threaded Rod, 1-m Long | https://github.com/ISS-Mimic/Mimic/blob/main/Wiki/Images/mmc_nut.png | | Support Rods for Inboard Truss Segment | 2 | $2.54 | $5.08 | [McMaster](https://www.mcmaster.com/98861A040/) | M3 Steel Threaded Rod, 1-m Long | <img src="https://github.com/ISS-Mimic/Mimic/blob/main/Wiki/Images/mmc_nut.png" width="200">
M3 Locknuts | 1 | $4.65 | $4.65 | McMaster | https://www.mcmaster.com/90576A102/ | M3 Steel Nylon-Insert Locknut (Pkg 100) | https://github.com/ISS-Mimic/Mimic/blob/main/Wiki/Images/mmc_threadedrod.png | | M3 Locknuts | 1 | $4.65 | $4.65 | [McMaster](https://www.mcmaster.com/90576A102/) | M3 Steel Nylon-Insert Locknut (Pkg 100) | <img src="https://github.com/ISS-Mimic/Mimic/blob/main/Wiki/Images/mmc_threadedrod.png" width="200">
Bamboo Skewers for attaching module halves | 1 | $5.99 | $5.99 | Amazon | https://www.amazon.com/Appetiser-Cocktail-Chocolate-Fountain-Barbecue/dp/B07MY7XVB1/ | HOPELF 6" Natural Bamboo Skewers, Φ=4mm (100 pcs) | https://m.media-amazon.com/images/I/61MhlR2cAtL._AC_SL1500_.jpg | | Bamboo Skewers for attaching module halves | 1 | $5.99 | $5.99 | [Amazon](https://www.amazon.com/Appetiser-Cocktail-Chocolate-Fountain-Barbecue/dp/B07MY7XVB1/) | HOPELF 6" Natural Bamboo Skewers, Φ=4mm (100 pcs) | <img src="https://m.media-amazon.com/images/I/61MhlR2cAtL._AC_SL1500_.jpg" width="200">
Cyanoacrylate Glue | 1 | $9.49 | $9.49 | Amazon | https://www.amazon.com/Gorilla-105801-Super-1-Pack-Clear/dp/B08QR2XRKD | Gorilla Super Glue Gel (any "superglue" should work) | https://m.media-amazon.com/images/I/81kAtvCkeBS._AC_SL1500_.jpg | | Cyanoacrylate Glue | 1 | $9.49 | $9.49 | [Amazon](https://www.amazon.com/Gorilla-105801-Super-1-Pack-Clear/dp/B08QR2XRKD) | Gorilla Super Glue Gel (any "superglue" should work) | <img src="https://m.media-amazon.com/images/I/81kAtvCkeBS._AC_SL1500_.jpg" width="200">
Metallic Gold Vinyl for Solar Arrays | 2 | $11.99 | $23.98 | Amazon | https://www.amazon.com/gp/product/B07XZ3XY42/ | (Not Required - Aesthetic Purposes Only) Metallic Gold Vinyl (12"x6') | https://images-na.ssl-images-amazon.com/images/I/61XFjfy35XL._AC_SL1500_.jpg | | Metallic Gold Vinyl for Solar Arrays | 2 | $11.99 | $23.98 | [Amazon](https://www.amazon.com/gp/product/B07XZ3XY42/) | (Not Required - Aesthetic Purposes Only) Metallic Gold Vinyl (12"x6') | <img src="https://images-na.ssl-images-amazon.com/images/I/61XFjfy35XL._AC_SL1500_.jpg" width="200">
Ultraviolet Blue Vinyl for Solar Arrays | 2 | $12.69 | $25.38 | Amazon | https://www.amazon.com/gp/product/B07QYXHM9H/ | (Not Required - Aesthetic Purposes Only) Ultraviolet Blue Vinyl (12"x 48") | https://github.com/ISS-Mimic/Mimic/assets/58833710/6a3dd56d-9eb3-4495-8b58-9b9101e909ea | | Ultraviolet Blue Vinyl for Solar Arrays | 2 | $12.69 | $25.38 | [Amazon](https://www.amazon.com/gp/product/B07QYXHM9H/) | (Not Required - Aesthetic Purposes Only) Ultraviolet Blue Vinyl (12"x 48") | <img src="https://github.com/ISS-Mimic/Mimic/assets/58833710/6a3dd56d-9eb3-4495-8b58-9b9101e909ea" width="200">
Metallic Champagne Gold Vinyl for Solar Arrays | 2 | $12.29 | $24.58 | Amazon | https://www.amazon.com/gp/product/B088TMQ3Q6/ | (Not Required - Aesthetic Purposes Only) Ultraviolet Blue Vinyl (12"x 48") | https://github.com/ISS-Mimic/Mimic/assets/58833710/acfa16c5-2f17-4bac-9d11-94584da22d7e | | Metallic Champagne Gold Vinyl for Solar Arrays | 2 | $12.29 | $24.58 | [Amazon](https://www.amazon.com/gp/product/B088TMQ3Q6/) | (Not Required - Aesthetic Purposes Only) Ultraviolet Blue Vinyl (12"x 48") | <img src="https://github.com/ISS-Mimic/Mimic/assets/58833710/acfa16c5-2f17-4bac-9d11-94584da22d7e" width="200">
 |  |  |  |  |  |  |  | | **Subtotal** | **Subtotal + Vinyl**
 |  |  |  |  |  |  |  | | :---: | :---:
 |  | $94.60 | $168.54 |  |  |  |  | | $94.6 | $168.54
 |  |  |  |  |  |  |  | ### Frame
 |  |  |  |  |  |  |  | The frame will require black 2020 T-slot aluminum in these lengths and quantities:
 |  |  |  |  |  |  |  | * 600mm x 4
 |  |  |  |  |  |  |  | * 300mm x 6
 |  |  |  |  |  |  |  | * 50 mm x 3 (not a standard length)
 |  |  |  |  |  |  |  | * It also requires a single length of black 2040 T-slot aluminum, 1300mm long (not a standard length).
 |  |  |  |  |  |  |  | Due to the few requiring custom cuts and the way things are priced, it's easiest to order as listed here and in the BOM table below. Cuts cost $1.50 each at Zyltech.
 |  |  |  |  |  |  |  | * (Qty 1) 2000mm 2040 black T-slot aluminum, cut to 1300mm
 |  |  |  |  |  |  |  | * (Qty 5) 1000mm 2020 black T-slot aluminum, cut to (4) 600mm, (6) 300mm, (3) 50mm.
 |  |  |  |  |  |  |  | * Include a note that says "Please include cutoff pieces in shipment" so you have those for your next project.
 |  |  |  |  |  |  |  | | **Part** | **Quantity** | **Cost Per Unit** | **Total Cost** | **URL** | **Notes** | **Image**
Part | Quantity | Cost Per Unit | Total Cost | Part URL Name | Part URL | Notes | Image URL | | ---- | :--: | :--: | :--: | --- | ---- | ---
Black Frame Base 2040 Choose 2000mm (cut request on following line item) | 1 | $26.95 | $26.95 | Zyltech | https://www.zyltech.com/zyltech-2040-anodized-aluminum-extrusion-pre-cut-lengths-300mm-2000mm/ | ZYLtech 2040 Anodized Aluminum Extrusion Pre-cut lengths: choose 2000mm (later cut to 1300mm) | https://cdn11.bigcommerce.com/s-eblil3q2nd/images/stencil/1280x1280/products/870/17552/2040_final__73686__59855__46593.1679345657.jpg | | Black Frame Base 2040 Choose 2000mm (cut request on following line item) | 1 | $26.95 | $26.95 | [Zyltech](https://www.zyltech.com/zyltech-2040-anodized-aluminum-extrusion-pre-cut-lengths-300mm-2000mm/) | ZYLtech 2040 Anodized Aluminum Extrusion Pre-cut lengths: choose 2000mm (later cut to 1300mm) | <img src="https://cdn11.bigcommerce.com/s-eblil3q2nd/images/stencil/1280x1280/products/870/17552/2040_final__73686__59855__46593.1679345657.jpg" width="200">
Cut request for Black Frame Base (2040) from above: request cut to 1300mm | 1 | $1.50 | $1.50 | Zyltech | https://www.zyltech.com/aluminum-extrusion-custom-cut-service/ | Aluminum Extrusion Custom Cut Service - Request 1300mm | https://cdn11.bigcommerce.com/s-eblil3q2nd/images/stencil/1280x1280/products/403/16616/Custom_Cut_Image__80342__48138.1665254999.jpg | | Cut request for Black Frame Base (2040) from above: request cut to 1300mm | 1 | $1.5 | $1.5 | [Zyltech](https://www.zyltech.com/aluminum-extrusion-custom-cut-service/) | Aluminum Extrusion Custom Cut Service - Request 1300mm | <img src="https://cdn11.bigcommerce.com/s-eblil3q2nd/images/stencil/1280x1280/products/403/16616/Custom_Cut_Image__80342__48138.1665254999.jpg" width="200">
Frame - Supports, Black 2020 1000mm segments (cut request on following line item) | 5 | $9.95 | $49.75 | Zyltech | https://www.zyltech.com/zyltech-black-2020-aluminum-extrusion-pre-cut-lengths-300mm-2000mm/ | ZYLtech Black 2020 Aluminum Extrusion - Pre-cut lengths: choose 1000mm | https://cdn11.bigcommerce.com/s-eblil3q2nd/images/stencil/1280x1280/products/866/17522/Image_1__63675__01672__98065.1676663189.jpg | | Frame - Supports, Black 2020 1000mm segments (cut request on following line item) | 5 | $9.95 | $49.75 | [Zyltech](https://www.zyltech.com/zyltech-black-2020-aluminum-extrusion-pre-cut-lengths-300mm-2000mm/) | ZYLtech Black 2020 Aluminum Extrusion - Pre-cut lengths: choose 1000mm | <img src="https://cdn11.bigcommerce.com/s-eblil3q2nd/images/stencil/1280x1280/products/866/17522/Image_1__63675__01672__98065.1676663189.jpg" width="200">
Cut request for Black Frame Supports (2020) from above: request cut to lengths as defined in Notes | 13 | $1.50 | $19.50 | Zyltech | https://www.zyltech.com/aluminum-extrusion-custom-cut-service/ | Aluminum Extrusion Custom Cut Service - cut to (4) 600mm, (6) 300mm, (3) 50mm | https://cdn11.bigcommerce.com/s-eblil3q2nd/images/stencil/1280x1280/products/403/16616/Custom_Cut_Image__80342__48138.1665254999.jpg | | Cut request for Black Frame Supports (2020) from above: request cut to lengths as defined in Notes | 13 | $1.5 | $19.5 | [Zyltech](https://www.zyltech.com/aluminum-extrusion-custom-cut-service/) | Aluminum Extrusion Custom Cut Service - cut to (4) 600mm, (6) 300mm, (3) 50mm | <img src="https://cdn11.bigcommerce.com/s-eblil3q2nd/images/stencil/1280x1280/products/403/16616/Custom_Cut_Image__80342__48138.1665254999.jpg" width="200">
Frame Support L-brackets (small) | 1 | $6.95 | $6.95 | Zyltech | http://www.zyltech.com/12x-90-20mm-aluminum-brace-angle-bracket-for-2020-extrusion-black/ | 12x 90° 20mm Aluminum Brace/Angle Bracket for 2020 Extrusion - Black (12 per pack, total of 5 brackets needed) | https://cdn11.bigcommerce.com/s-eblil3q2nd/images/stencil/1280x1280/products/123/15917/s136714152818872222_p319_i12_w2560__66787__47030.1665254751.jpg | | Frame Support L-brackets (small) | 1 | $6.95 | $6.95 | [Zyltech](http://www.zyltech.com/12x-90-20mm-aluminum-brace-angle-bracket-for-2020-extrusion-black/) | 12x 90° 20mm Aluminum Brace/Angle Bracket for 2020 Extrusion - Black (12 per pack, total of 5 brackets needed) | <img src="https://cdn11.bigcommerce.com/s-eblil3q2nd/images/stencil/1280x1280/products/123/15917/s136714152818872222_p319_i12_w2560__66787__47030.1665254751.jpg" width="200">
Frame Support L-brackets (large) | 2 | $7.95 | $15.90 | Zyltech | http://www.zyltech.com/12x-90-2028-aluminum-corner-brace-angle-bracket-for-2020-extrusion-black/ | 12x 90° 2028 Aluminum Corner Brace/Angle Bracket for 2020 Extrusion - Black (12 per pack, total of 22 brackets needed) | https://cdn11.bigcommerce.com/s-eblil3q2nd/images/stencil/1280x1280/products/317/16468/s136714152818872222_p240_i11_w2560__48692__70496.1669392451.jpg | | Frame Support L-brackets (large) | 2 | $7.95 | $15.9 | [Zyltech](http://www.zyltech.com/12x-90-2028-aluminum-corner-brace-angle-bracket-for-2020-extrusion-black/) | 12x 90° 2028 Aluminum Corner Brace/Angle Bracket for 2020 Extrusion - Black (12 per pack, total of 22 brackets needed) | <img src="https://cdn11.bigcommerce.com/s-eblil3q2nd/images/stencil/1280x1280/products/317/16468/s136714152818872222_p240_i11_w2560__48692__70496.1669392451.jpg" width="200">
T-plate - black (for stabilization) | 4 | $1.95 | $7.80 | Zyltech | https://www.zyltech.com/2020-90-degree-t-joining-plate-black/ | 2020 90 Degree T Joining Plate - Black | https://cdn11.bigcommerce.com/s-eblil3q2nd/images/stencil/1280x1280/products/643/16947/Black_2020-2__56624__66793.1665255100.jpg | | T-plate - black (for stabilization) | 4 | $1.95 | $7.8 | [Zyltech](https://www.zyltech.com/2020-90-degree-t-joining-plate-black/) | 2020 90 Degree T Joining Plate - Black | <img src="https://cdn11.bigcommerce.com/s-eblil3q2nd/images/stencil/1280x1280/products/643/16947/Black_2020-2__56624__66793.1665255100.jpg" width="200">
Spring Loaded T-Nuts | 1 | $12.95 | $12.95 | Zyltech | https://www.zyltech.com/100x-zyltech-spring-loaded-t-nuts-for-2020-aluminum-extrusion-m4-or-m5/ | 100x ZYLtech Spring Loaded T-Nuts for 2020 Aluminum Extrusion - M5 (total of 74 nuts needed) | https://cdn11.bigcommerce.com/s-eblil3q2nd/images/stencil/500x659/products/338/16493/s136714152818872222_p271_i12_w565__84245__88962.1665254952.jpg | | Spring Loaded T-Nuts | 1 | $12.95 | $12.95 | [Zyltech](https://www.zyltech.com/100x-zyltech-spring-loaded-t-nuts-for-2020-aluminum-extrusion-m4-or-m5/) | 100x ZYLtech Spring Loaded T-Nuts for 2020 Aluminum Extrusion - M5 (total of 74 nuts needed) | <img src="https://cdn11.bigcommerce.com/s-eblil3q2nd/images/stencil/500x659/products/338/16493/s136714152818872222_p271_i12_w565__84245__88962.1665254952.jpg" width="200">
Frame Screws | 1 | $3.95 | $3.95 | Zyltech | https://www.zyltech.com/100x-zyltech-m5x8-and-m5x10-button-hex-screws/ | 100x ZYLtech M5x8 Button Hex Screws: choose M5x8 (total of 74 screws needed) | https://cdn11.bigcommerce.com/s-eblil3q2nd/images/stencil/500x659/products/332/16488/Screws_Image_2__83478__71704.1665254948.jpg | | Frame Screws | 1 | $3.95 | $3.95 | [Zyltech](https://www.zyltech.com/100x-zyltech-m5x8-and-m5x10-button-hex-screws/) | 100x ZYLtech M5x8 Button Hex Screws: choose M5x8 (total of 74 screws needed) | <img src="https://cdn11.bigcommerce.com/s-eblil3q2nd/images/stencil/500x659/products/332/16488/Screws_Image_2__83478__71704.1665254948.jpg" width="200">
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

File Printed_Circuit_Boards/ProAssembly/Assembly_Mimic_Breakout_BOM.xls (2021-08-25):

Comment | Designator | Footprint | LCSC Part #（optional）
HDMI | J1 | HDMI-SMD | C138388
Screw Terminal | J2-3 | CONN-TH_6P-P2.54_KF128-2.54-6P | C474924
Header Pins | J4 | HDR-TH_3P-P2.54-V-M | C225478
ZH JST | J5-6 | CONN-TH-6P-P1.50_B6B-ZR_LF_SN | C157984

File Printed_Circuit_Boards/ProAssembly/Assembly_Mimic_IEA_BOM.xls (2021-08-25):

Comment | Designator | Footprint | LCSC Part #（optional）
WS2812B | U1-6 | LED-4_5050 | C114587
ZH JST | J2 | CONN-TH-6P-P1.50_B6B-ZR_LF_SN | C157984

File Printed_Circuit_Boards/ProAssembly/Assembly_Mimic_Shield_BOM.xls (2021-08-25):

Comment | Designator | Footprint | LCSC Part #（optional）
Red | D1-8 | LED_0603 | C72044
10k | R1-8 | R0603 | C103210
HDMI | J7-8 | HDMI-SMD | C138388
Connector | J1-4 | CONN-TH_P2.54_KF128-2.54-2P | C474920
Headers | J5 | HDR-TH_2P-P2.54-V-M | C492401

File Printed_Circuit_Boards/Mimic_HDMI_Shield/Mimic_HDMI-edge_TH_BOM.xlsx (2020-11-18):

Designator | Manufacturer Part Number or Seeed SKU | Notes | Qty | Link
D1,D2,D3,D4,D5,D6,D7,D8 |  | Generic Through Hole 3mm LED | 8 | https://www.amazon.com/Diffused-Lighting-Electronics-Components-Emitting/dp/B01C3W6NSK/
R1,R2,R3,R4,R5,R6,R7,R8 |  | Generic Through Hole 10k Resistor | 8 | https://www.amazon.com/Projects-100EP51210K0-10k-Resistors-Pack/dp/B0185FIOTA/
U1,U2 | a14070400ux0603 | HDMI Edge Connectors | 2 | https://www.amazon.com/gp/product/B00R1J8L0O/ http://www.uxcell.com/5pcs-16mm-spacing-gold-tone-mini-19pin-hdmi-female-connector-smt-180-degree-p-627352.html
J1 |  | 1x2 2.54mm Header | 1 | https://www.amazon.com/MCIGICM-Header-2-45mm-Arduino-Connector/dp/B07PKKY8BX/
J2 |  | 1x4 2.54mm Header | 1
J7 |  | 1x6 2.54mm Header | 1
J8 |  | 1x5 2.54mm Header | 1
J9 |  | 1x7 2.54mm Header | 1
J10 |  | 1x8 2.54mm Header | 1
M1,M2,M3,M4 |  | 2pin 2.54mm Screw Terminal | 4 | https://www.amazon.com/gp/product/B07WKL6MRM/

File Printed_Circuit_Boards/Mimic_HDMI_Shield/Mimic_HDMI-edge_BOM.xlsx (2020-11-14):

Designator | Manufacturer Part Number or Seeed SKU | Notes | Qty | Link
D1,D2,D3,D4,D5,D6,D7,D8 | ADL-0603W | Generic 0603 LED | 8 | https://www.amazon.com/Assorted-Lighting-Electronics-Components-Emitting/dp/B01CUGA380/
R1,R2,R3,R4,R5,R6,R7,R8 | RC0603FR-0710KL | Generic 0603 10k Resistor | 8 | https://www.amazon.com/uxcell-Resistor-Resistors-Tolerance-300pcs/dp/B07QFNZXZZ/
U1,U2 | a14070400ux0603 | HDMI Edge Connectors | 2 | https://www.amazon.com/gp/product/B00R1J8L0O/ http://www.uxcell.com/5pcs-16mm-spacing-gold-tone-mini-19pin-hdmi-female-connector-smt-180-degree-p-627352.html
J1 |  | 1x2 2.54mm Header | 1 | https://www.amazon.com/MCIGICM-Header-2-45mm-Arduino-Connector/dp/B07PKKY8BX/
J2 |  | 1x4 2.54mm Header | 1
J7,J8 |  | 1x6 2.54mm Header | 2
J9,J10 |  | 1x8 2.54mm Header | 2
M1,M2,M3,M4 |  | 2pin 2.54mm Screw Terminal | 4 | https://www.amazon.com/gp/product/B07WKL6MRM/

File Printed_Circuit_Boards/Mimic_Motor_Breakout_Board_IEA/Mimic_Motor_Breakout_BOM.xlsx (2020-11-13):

Designator | Manufacturer Part Number or Seeed SKU | Notes | Qty | Link
J1 |  | Screw Terminal 8-pin 2.54mm pitch | 1 | https://www.amazon.com/Hxchen-8-Pin-2-54mm-Terminal-Connector/dp/B07WR6LM92/
J2 |  | 6pin JST ZH Motor Connector | 1 | https://www.amazon.com/1-5MM-Female-Double-Connector-Cable/dp/B07HSZJ2PM/
U1,U2,U3,U4,U5,U6 |  | WS2812B Neopixels, 6x per motor board package comes with 10 | 6 | https://www.digikey.com/catalog/en/partgroup/ws2812b-5050-rgb-led/51979

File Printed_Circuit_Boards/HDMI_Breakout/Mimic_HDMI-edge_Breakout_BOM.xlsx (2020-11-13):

Designator | Manufacturer Part Number or Seeed SKU | Notes | Qty | Link
J1 | a14070400ux0603 | HDMI Edge Connectors | 1 | https://www.amazon.com/gp/product/B00R1J8L0O/ http://www.uxcell.com/5pcs-16mm-spacing-gold-tone-mini-19pin-hdmi-female-connector-smt-180-degree-p-627352.html
J2,J4 |  | Screw Terminal 6-pin 2.54mm pitch | 2 | https://www.amazon.com/gp/product/B07S212CF8/
J3 |  | 1x3 2.54mm Header | 1 | https://www.amazon.com/MCIGICM-Header-2-45mm-Arduino-Connector/dp/B07PKKY8BX/
J5,J6 |  | 6pin JST ZH Motor Connector | 1 | https://www.amazon.com/1-5MM-Female-Double-Connector-Cable/dp/B07HSZJ2PM/

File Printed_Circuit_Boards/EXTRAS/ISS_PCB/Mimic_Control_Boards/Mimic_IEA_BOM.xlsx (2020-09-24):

Designator | Manufacturer Part Number or Seeed SKU | Qty | Link
WS2812B | 1528-1104-ND | 6 | https://www.digikey.com/catalog/en/partgroup/ws2812b-5050-rgb-led/51979

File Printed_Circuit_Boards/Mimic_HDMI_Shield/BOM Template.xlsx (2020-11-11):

Designator | Manufacturer Part Number or Seeed SKU | Qty | Link
D1,D2,D3,D4,D5,D6,D7,D8 | LTST-C191KSKT | 8 | https://www.seeedstudio.com/opl.html
R1,R2,R3,R4,R5,R6,R7,D8 | 0603WAF1002T5E | 8 | https://file.elecfans.com/web1/M00/61/0C/o4YBAFt-dwWACUP4AAh1Wgzv73Y460.pdf
J1,J2 | 1747981-1 | 2 | https://www.seeedstudio.com/opl.html

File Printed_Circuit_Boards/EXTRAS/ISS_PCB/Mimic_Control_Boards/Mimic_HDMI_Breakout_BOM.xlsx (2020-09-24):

Designator | Manufacturer Part Number or Seeed SKU | Qty | Link
J1 | 1747981-1 | 1 | https://www.seeedstudio.com/opl.html

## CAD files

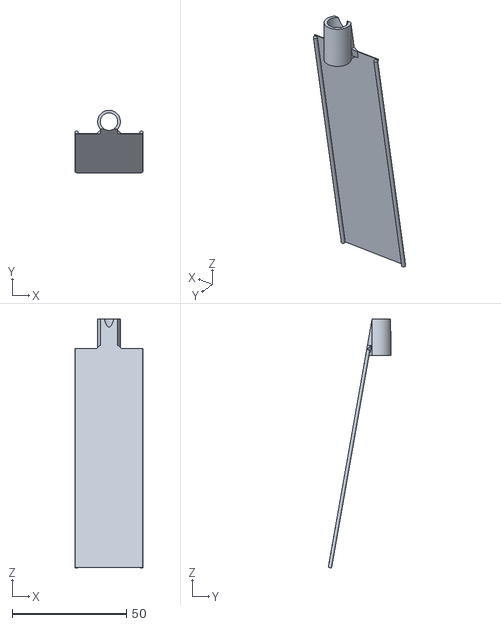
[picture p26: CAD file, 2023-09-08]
EXTRAs/Mini/3D_Printing/iROSA/0p5_Mimic_IROSA_Array_Main.stl
30.0 x 27.4 x 109.2

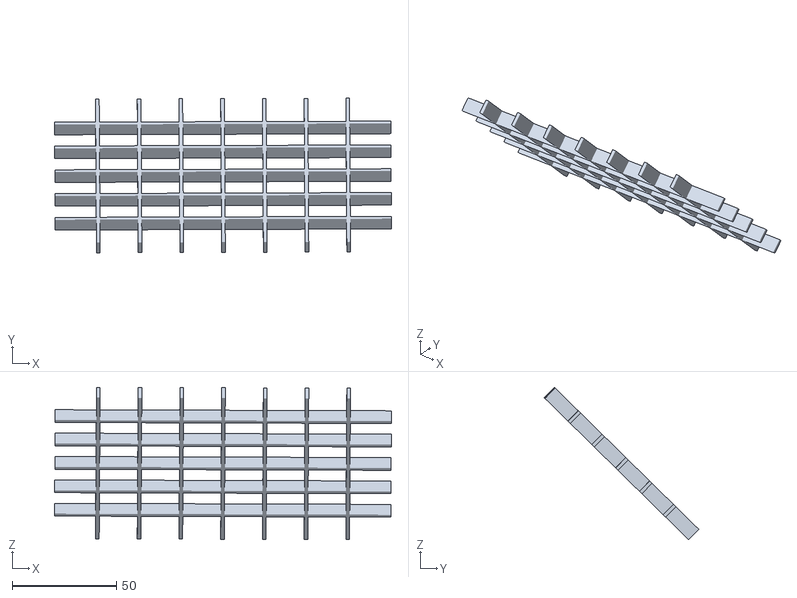
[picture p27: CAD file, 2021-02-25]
EXTRAs/SASA/Main_Ribs.stl
161.5 x 74.1 x 73.0

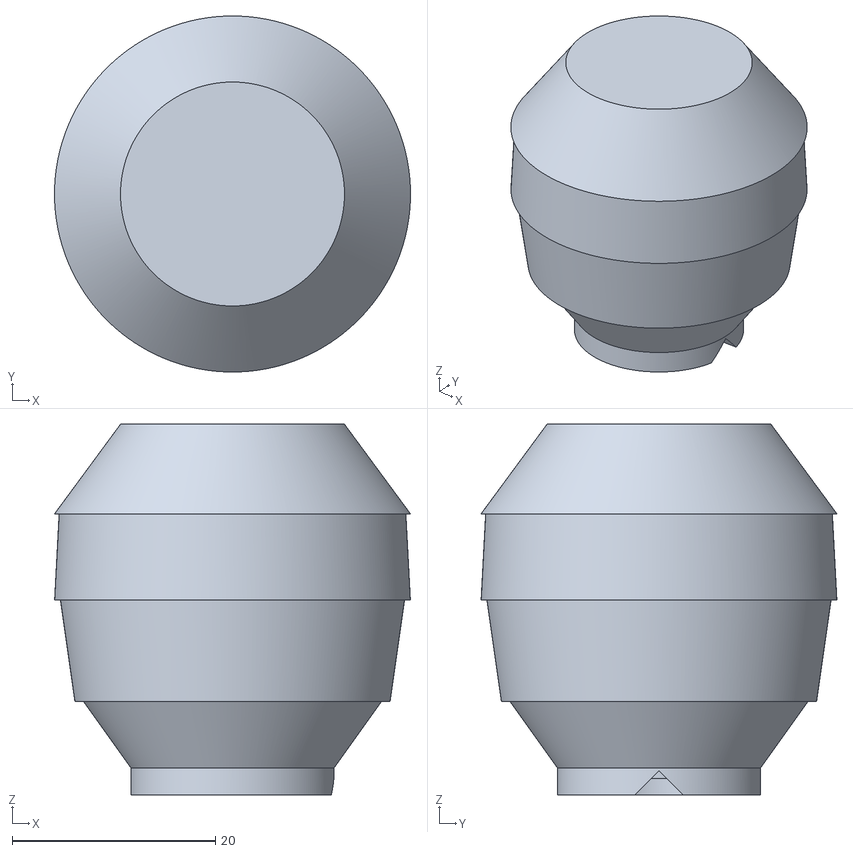
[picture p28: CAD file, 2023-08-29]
3D_Printing/BEAM/HiFi_BEAM.stl
35.0 x 35.0 x 36.5

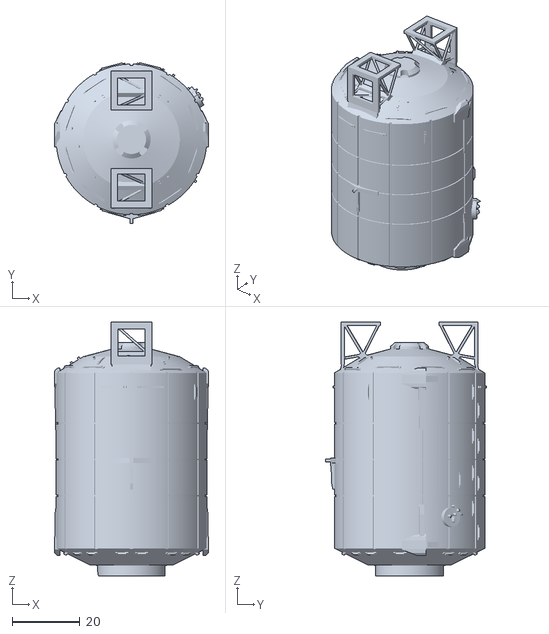
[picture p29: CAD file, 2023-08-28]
3D_Printing/Columbus/HiFi_Columbus.stl
45.6 x 47.5 x 75.0

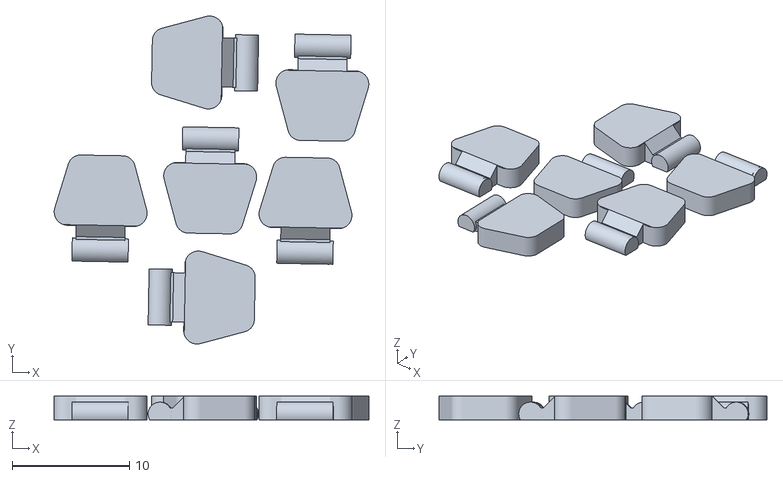
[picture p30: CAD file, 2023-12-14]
3D_Printing/Cupola/HiFi_Cupola_Shutters_6x.stl
26.9 x 28.0 x 2.02

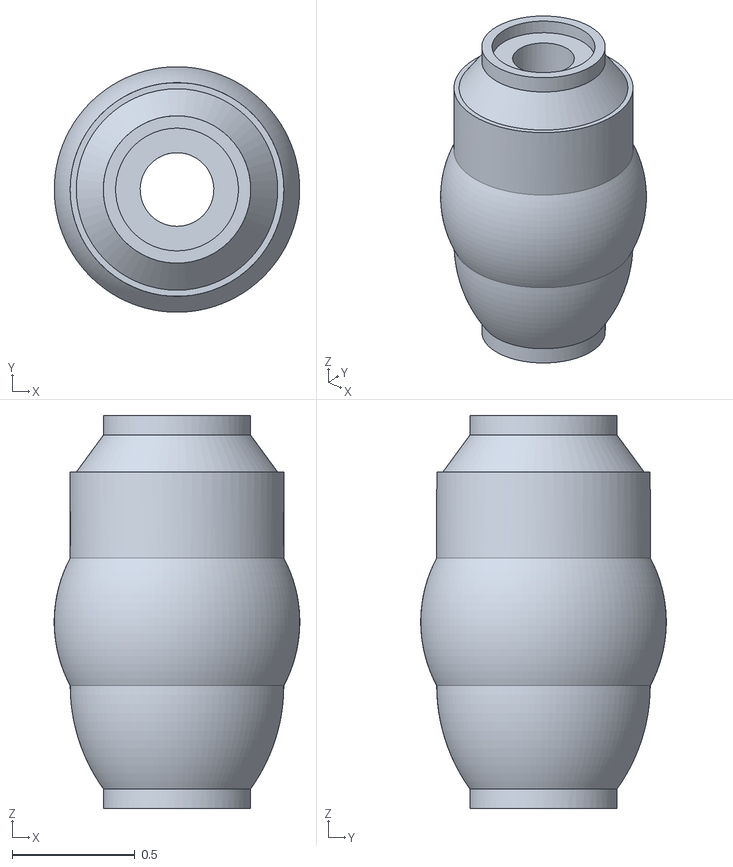
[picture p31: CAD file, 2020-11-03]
3D_Printing/DC_1_Pirs/LoFi_DockingCompartment.stl
1 x 1 x 1.60

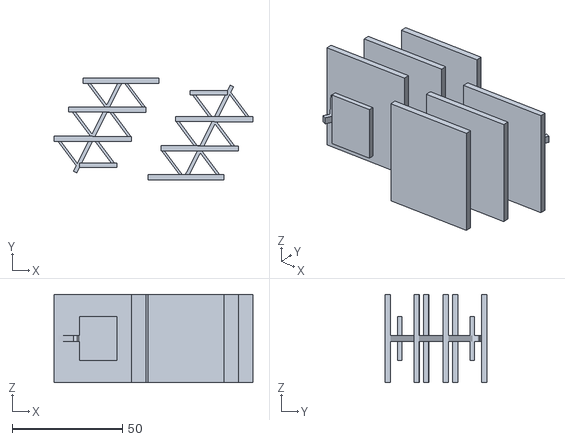
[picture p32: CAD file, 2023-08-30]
3D_Printing/FGB_Zarya/HiFi_FGB_Arrays.stl
90.1 x 46.1 x 40.0

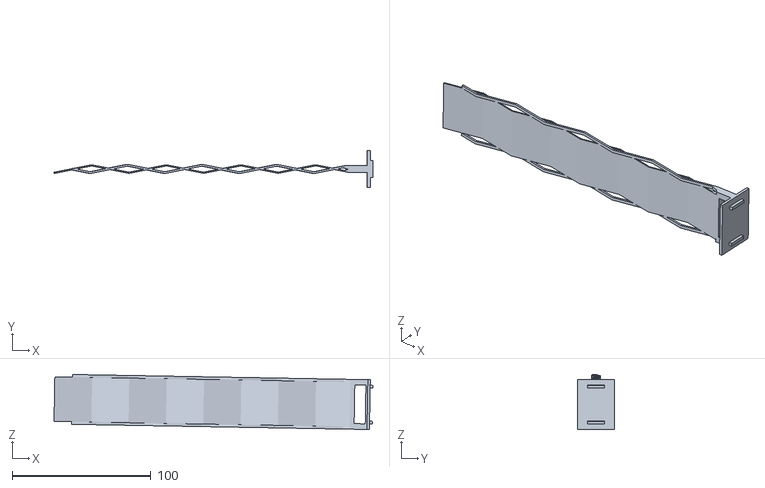
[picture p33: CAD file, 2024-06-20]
3D_Printing/HRS_Radiator_Wing/HRS_Radiator_OnePiece.stl
230.2 x 26.6 x 39.7

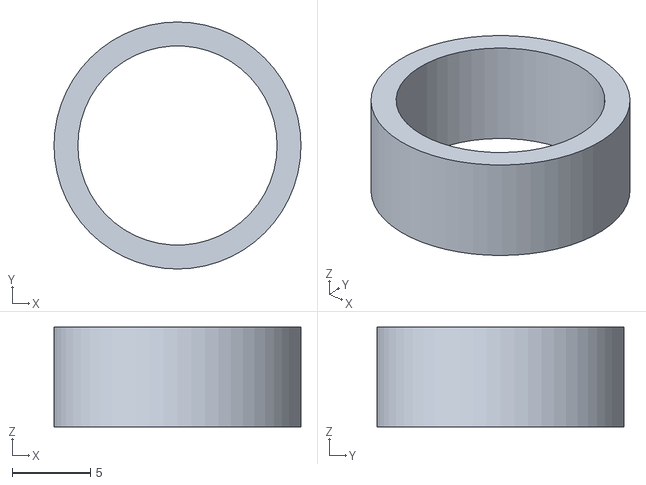
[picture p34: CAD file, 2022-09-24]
3D_Printing/IDA/LoFi_IDA23.stl
15.7 x 15.7 x 6.35

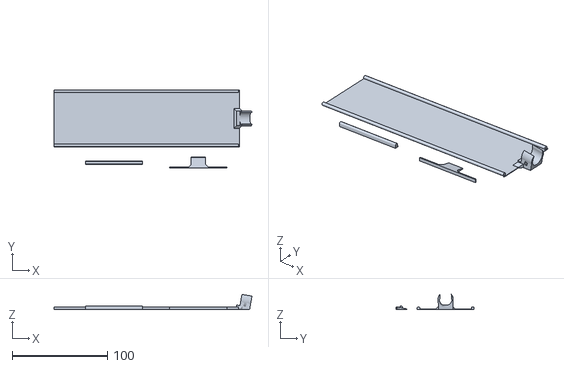
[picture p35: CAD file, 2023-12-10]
3D_Printing/IPA_Roll_Out_Solar_Arrays/HiFi_IROSA_Set.stl
208.1 x 82.3 x 16.1

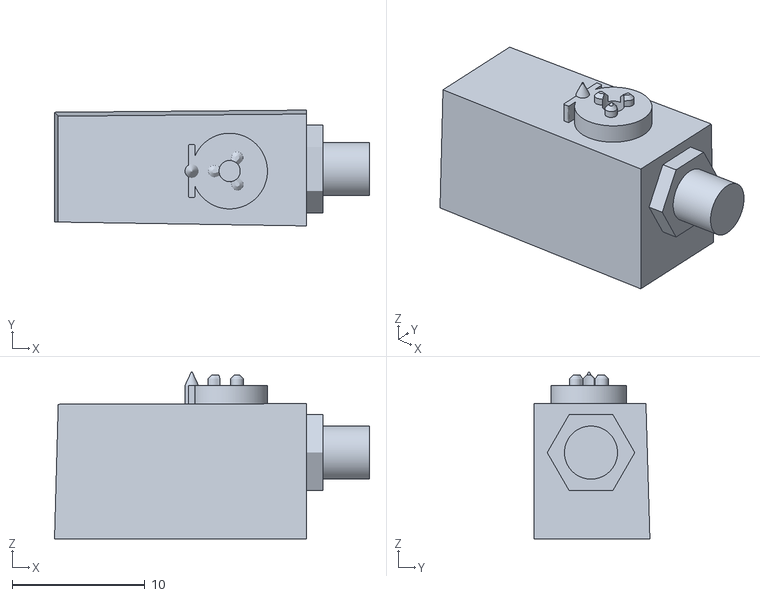
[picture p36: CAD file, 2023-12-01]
3D_Printing/JEM_EF/HiFi_JEM_EFU_Boxy.stl
23.7 x 8.73 x 12.6

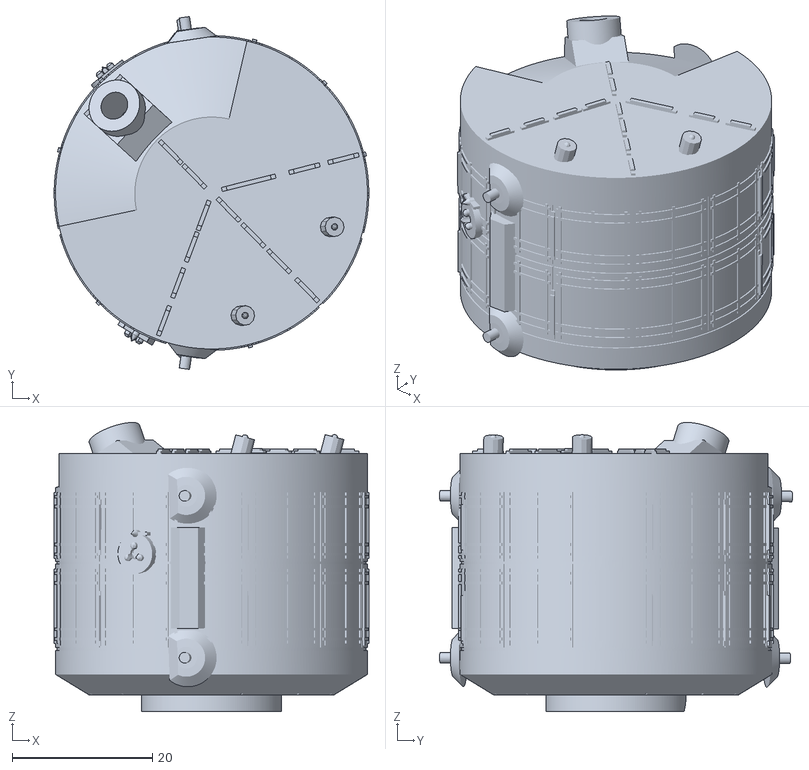
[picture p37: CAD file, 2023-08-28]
3D_Printing/JEM_ELM_PS/HiFi_JEM_JLP.stl
44.9 x 50.4 x 41.2

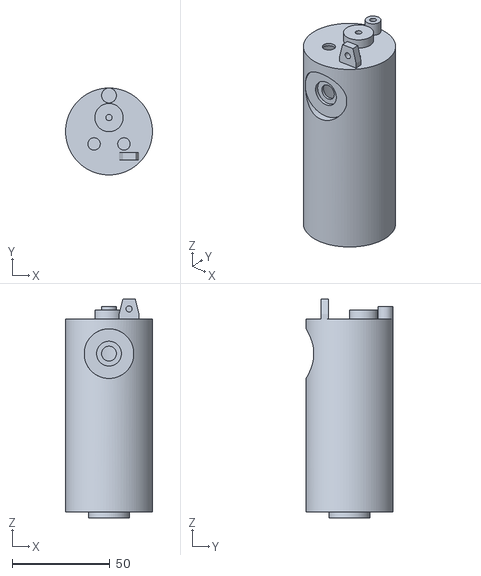
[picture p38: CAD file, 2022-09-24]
3D_Printing/JEM_Kibo/LoFi_JEM-PM.stl
44.4 x 44.4 x 112.0

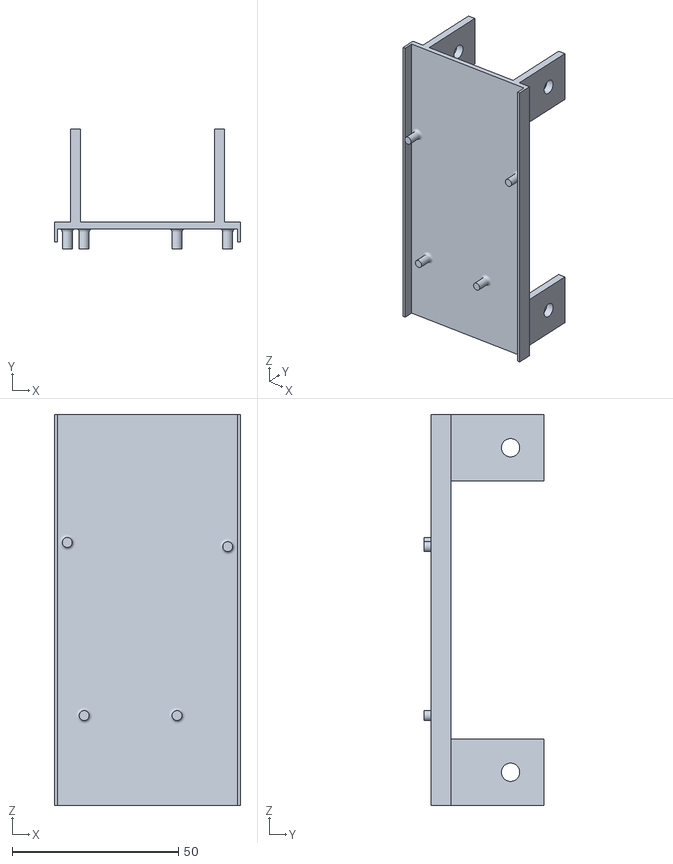
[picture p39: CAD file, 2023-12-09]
3D_Printing/Mimic_Structural_Compoments/Microcontroller_Mount_for_SARJ_TRRJ_Controller.stl
56.0 x 36.0 x 117.6

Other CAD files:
3D_Printing/AMS/dummy3_test.stl
3D_Printing/MLM_Nauka/HiFi_MLM_Arrays.stl
3D_Printing/MRM_1_Rassvet/LoFi_MRM1.stl
3D_Printing/Node_1_Unity/LoFi_UnityNode1-v2b.stl
3D_Printing/AMS/_dummy_test.stl
3D_Printing/AMS/dummy1_test.stl
3D_Printing/AMS/dummy2_test.stl
3D_Printing/AMS/dummy_test.stl
3D_Printing/BEAM/HiFi_BEAM_Cap.stl
3D_Printing/BEAM/LoFi_BEAM.stl
3D_Printing/Columbus/LoFi_COF-End.stl
3D_Printing/Columbus/LoFi_LEO-COF-barrel.stl
3D_Printing/Columbus/LoFi_Leonardo_End.stl
3D_Printing/Cupola/Cupola-Body.stl
3D_Printing/Cupola/Cupola-SideWindow.stl
3D_Printing/Cupola/Cupola-TopWindow.stl
3D_Printing/Cupola/HiFi_Cupola.stl
3D_Printing/FGB_Zarya/HiFi_FGB.stl
3D_Printing/HRS_Radiator_Wing/HiFi_HRS_Radiator.stl
3D_Printing/HRS_Radiator_Wing/HiFi_HRS_Radiator_Wing.f3d
3D_Printing/HRS_Radiator_Wing/HiFi_HRS_Radiator_Wing.step
3D_Printing/HRS_Radiator_Wing/HiFi_Radiator_Beam.stl
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

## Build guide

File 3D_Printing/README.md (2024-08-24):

This folder contains all of the original ISS Mimic 1:100 Scale Model STL files. 

A copy of the full integrated CAD model can be downloaded here: https://www.dropbox.com/scl/fo/itmwigxm0pkg0edz0na1k/AHoQr9Ibd3YKfEYgGv6ADOc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

This model contains all of the structure, print files, and cabling to help you build an ISS Mimic or adapt these models for your own use.

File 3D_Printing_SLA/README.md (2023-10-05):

SLA Print Models. Unless otherwise marked assume they are works in progress. Pre-supported models have all been verified in at least one test print and may lack refinement.

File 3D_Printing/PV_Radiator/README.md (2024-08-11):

# P4 PVR
Uhhh this is completely not necessary but the P4 PVR has a giant hole in it from an orbital debris impact so I had to model that - feel free to just print 4x PVRs and ignore it ;)

# Slicer Recommendation 

|  **Sub-Assembly / Module Name** | **STL Name & Link** | **Qty** | **Filament Color** | **Slicer Comments** | **Approx Print Time [h:mm]** | **Approx Filament Used [g]** | **Approx Filament Used [m]** |
| ---- | --- | --- | --- | --- | --- | --- | --- |
| PV Radiator (Outboard) | [HiFi_PVR.stl](https://github.com/ISS-Mimic/Mimic/blob/main/3D_Printing/PV_Radiator/HiFi_PVR.stl) | 3 | White | 0.12mm;10%;supports | 12:45 | 42 | 14.4 |
|  | [HiFi_PVR_P4.stl](https://github.com/ISS-Mimic/Mimic/blob/main/3D_Printing/PV_Radiator/HiFi_PVR_P4.stl) | 1 | White | 0.12mm;10%;supports | 4:14 | 14 | 4.8 |



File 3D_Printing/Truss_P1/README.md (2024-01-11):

# Slicer Recommendation 

|  **Sub-Assembly / Module Name** | **STL Name & Link** | **Qty** | **Filament Color** | **Slicer Comments** | **Approx Print Time [h:mm]** | **Approx Filament Used [g]** | **Approx Filament Used [m]** |
| ---- | --- | --- | --- | --- | --- | --- | --- |
| Truss_P1 | [LoFi_ITS-P1.stl](https://github.com/ISS-Mimic/Mimic/blob/main/3D_Printing/Truss_P1/LoFi_ITS-P1.stl) | 2 | White | 0.12mm;10%;supports| 13:00 | 98 | 32.85 |



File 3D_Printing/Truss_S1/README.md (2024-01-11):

# Slicer Recommendation 

|  **Sub-Assembly / Module Name** | **STL Name & Link** | **Qty** | **Filament Color** | **Slicer Comments** | **Approx Print Time [h:mm]** | **Approx Filament Used [g]** | **Approx Filament Used [m]** |
| ---- | --- | --- | --- | --- | --- | --- | --- |
| Truss S1 | [LoFi_ITS-1_AmmoniaTank.stl](https://github.com/ISS-Mimic/Mimic/blob/main/3D_Printing/Truss_S1/LoFi_ITS-1_AmmoniaTank.stl) | 2 | White | 0.12mm;10%;supports | 0:40 | 2.2 | 0.75 |

|  | [LoFi_ITS-1_Mounts.stl](https://github.com/ISS-Mimic/Mimic/blob/main/3D_Printing/Truss_S1/LoFi_ITS-1_Mounts.stl) | 2 | black | 0.12mm;10%;supports | 2:15 | 11.9 | 4 |

| Truss_S1 | [LoFi_ITS-S1_.stl](https://github.com/ISS-Mimic/Mimic/blob/main/3D_Printing/Truss_P1/LoFi_ITS-S1.stl) | 2 | White | 0.12mm;10%;supports| 13:00 | 98 | 32.85 |


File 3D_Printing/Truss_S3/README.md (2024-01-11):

# Slicer Recommendation 

|  **Sub-Assembly / Module Name** | **STL Name & Link** | **Qty** | **Filament Color** | **Slicer Comments** | **Approx Print Time [h:mm]** | **Approx Filament Used [g]** | **Approx Filament Used [m]** |
| ---- | --- | --- | --- | --- | --- | --- | --- |
|  | [LoFi_ITS-S3-complex.stl](https://github.com/ISS-Mimic/Mimic/blob/main/3D_Printing/Truss_S3/LoFi_ITS-S3-complex.stl) | 1 | White | 0.12mm;10%;supports | 5:08 | 28.8 | 9.7 |

|  | [LoFi_ITS-3_SARJ_Gear_Ring.stl](https://github.com/ISS-Mimic/Mimic/blob/main/3D_Printing/Truss_S3/LoFi_ITS-3_SARJ_Gear_Ring.stl) | 2 | White | 0.12mm;10%;supports | 0:48 | 4 | 1.32 |


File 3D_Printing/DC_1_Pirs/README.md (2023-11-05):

*THIS MODULE IS NO LONGER PART OF ISS CURRENT ASSEMBLY*

# Slicer Recommendation 

|  **Sub-Assembly / Module Name** | **STL Name & Link** | **Qty** | **Filament Color** | **Slicer Comments** | **Approx Print Time [h:mm]** | **Approx Filament Used [g]** | **Approx Filament Used [m]** |
| ---- | --- | --- | --- | --- | --- | --- | --- |
| Docking Compartment | [LoFi_DockingCompartment.stl](https://github.com/ISS-Mimic/Mimic/blob/main/3D_Printing/DC_1_Pirs/LoFi_DockingCompartment.stl) | 1 | Vanallia White | 0.12mm;10%;supports | 1:31 | 8.4 | 2.8 |



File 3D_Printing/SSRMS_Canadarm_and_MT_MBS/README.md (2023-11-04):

HiFi SSRMS model Credit: Canadian Space Agency https://www.asc-csa.gc.ca/eng/multimedia/search/image/10186

Modified slightly to work with ISS MIMIC model

# Slicer Recommendation 

|  **Sub-Assembly / Module Name** | **STL Name & Link** | **Qty** | **Filament Color** | **Slicer Comments** | **Approx Print Time [h:mm]** | **Approx Filament Used [g]** | **Approx Filament Used [m]** |
| ---- | --- | --- | --- | --- | --- | --- | --- |
| SSRMS Canadarm and MT MBS | [LoFi_Canadaarm2_Arm.stl](https://github.com/ISS-Mimic/Mimic/blob/main/3D_Printing/SSRMS_Canadarm_and_MT_MBS/LoFi_Canadaarm2_Arm.stl) | 2 | White | 0.12mm;10%;supports | 0:23 | 1.9 | 0.65 |
|  | [LoFi_Canadaarm2_EE.stl](https://github.com/ISS-Mimic/Mimic/blob/main/3D_Printing/SSRMS_Canadarm_and_MT_MBS/LoFi_Canadaarm2_EE.stl) | 2 | White | 0.12mm;10%;supports | - | - | - |

|  | [LoFi_MobileBaseSystem_Base.stl](https://github.com/ISS-Mimic/Mimic/blob/main/3D_Printing/SSRMS_Canadarm_and_MT_MBS/LoFi_MobileBaseSystem_Base.stl) | 1 | Silver | 0.12mm;10%;supports | 1:01 | 6.5 | 2.15 |
|  | [LoFi_MobileBaseSystem_Body.stl](https://github.com/ISS-Mimic/Mimic/blob/main/3D_Printing/SSRMS_Canadarm_and_MT_MBS/LoFi_MobileBaseSystem_Body.stl) | 1 | Silver | 0.12mm;10%;supports | - | - | - |


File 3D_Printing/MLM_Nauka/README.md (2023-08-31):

### Small differences from the FGB print

# Slicer Recommendation 

|  **Sub-Assembly / Module Name** | **STL Name & Link** | **Qty** | **Filament Color** | **Slicer Comments** | **Approx Print Time [h:mm]** | **Approx Filament Used [g]** | **Approx Filament Used [m]** |
| ---- | --- | --- | --- | --- | --- | --- | --- |
| MLM / Nauka Airlock | [LoFi-MLM-Airlock.stl](https://github.com/ISS-Mimic/Mimic/blob/main/3D_Printing/MLM_Nauka/LoFi-MLM-Airlock.stl) | 1 | White | 0.16mm;10%;supports | 1:10| 5.12 | 1.72 |
|  | [LoFi-MLM-Airlock-Hatch.stl](https://github.com/ISS-Mimic/Mimic/blob/main/3D_Printing/MLM_Nauka/LoFi-MLM-Airlock-Hatch.stl) | 1 | White | 0.16mm;10%;supports | - | - | - |



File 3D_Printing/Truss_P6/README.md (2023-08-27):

### This print is probably the most difficult print in the whole project. During post-processing removal of support material it is very easy to break the print. If you want to print the low fidelity truss, those files are located [here](https://github.com/ISS-Mimic/Mimic/tree/main/3D_Printing/Truss_S6). In the low fidelity build, P6 and S6 are the exact same model, however in the high fidelity build there are a few differences.

# Slicer Recommendation 

|  **Sub-Assembly / Module Name** | **STL Name & Link** | **Qty** | **Filament Color** | **Slicer Comments** | **Approx Print Time [h:mm]** | **Approx Filament Used [g]** | **Approx Filament Used [m]** |
| ---- | --- | --- | --- | --- | --- | --- | --- |
| Truss_P6 | [HiFi_Truss_P6.stl](https://github.com/ISS-Mimic/Mimic/blob/main/3D_Printing/Truss_P6/HiFi_Truss_P6.stl) | 1 | White | 0.12mm;10%;supports | 8:08 | 40.1 | 13.7 |



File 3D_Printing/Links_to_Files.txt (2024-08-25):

https://github.com/ISS-Mimic/Mimic/blob/main/3D_Printing/AMS/README.md
https://github.com/ISS-Mimic/Mimic/blob/main/3D_Printing/BEAM/HiFi_BEAM.stl
https://github.com/ISS-Mimic/Mimic/blob/main/3D_Printing/BEAM/HiFi_BEAM_Cap.stl
https://github.com/ISS-Mimic/Mimic/blob/main/3D_Printing/BEAM/README.md
https://github.com/ISS-Mimic/Mimic/blob/main/3D_Printing/Columbus/HiFi_Columbus.stl
https://github.com/ISS-Mimic/Mimic/blob/main/3D_Printing/Columbus/README.md
https://github.com/ISS-Mimic/Mimic/blob/main/3D_Printing/Cupola/HiFi_Cupola.stl
https://github.com/ISS-Mimic/Mimic/blob/main/3D_Printing/Cupola/HiFi_Cupola_Shutters_6x.stl
https://github.com/ISS-Mimic/Mimic/blob/main/3D_Printing/Cupola/README.md
https://github.com/ISS-Mimic/Mimic/blob/main/3D_Printing/ELC_1/README.md
https://github.com/ISS-Mimic/Mimic/blob/main/3D_Printing/ELC_2/README.md
https://github.com/ISS-Mimic/Mimic/blob/main/3D_Printing/ELC_3/README.md
https://github.com/ISS-Mimic/Mimic/blob/main/3D_Printing/ELC_4/README.md
https://github.com/ISS-Mimic/Mimic/blob/main/3D_Printing/ESP_1/README.md
https://github.com/ISS-Mimic/Mimic/blob/main/3D_Printing/ESP_2/README.md
https://github.com/ISS-Mimic/Mimic/blob/main/3D_Printing/ESP_3/README.md
https://github.com/ISS-Mimic/Mimic/blob/main/3D_Printing/EVA_Astronaut/EMU.stl
https://github.com/ISS-Mimic/Mimic/blob/main/3D_Printing/EVA_Astronaut/README.md
https://github.com/ISS-Mimic/Mimic/blob/main/3D_Printing/FGB_Zarya/HiFi_FGB.stl
https://github.com/ISS-Mimic/Mimic/blob/main/3D_Printing/FGB_Zarya/HiFi_FGB_Arrays.stl
https://github.com/ISS-Mimic/Mimic/blob/main/3D_Printing/FGB_Zarya/README.md
https://github.com/ISS-Mimic/Mimic/blob/main/3D_Printing/HRS_Radiator_Wing/HRS_Radiator_OnePiece.stl
https://github.com/ISS-Mimic/Mimic/blob/main/3D_Printing/HRS_Radiator_Wing/HiFi_HRS_Radiator.stl
https://github.com/ISS-Mimic/Mimic/blob/main/3D_Printing/HRS_Radiator_Wing/HiFi_HRS_Radiator_Wing.f3d
https://github.com/ISS-Mimic/Mimic/blob/main/3D_Printing/HRS_Radiator_Wing/HiFi_HRS_Radiator_Wing.step
https://github.com/ISS-Mimic/Mimic/blob/main/3D_Printing/HRS_Radiator_Wing/HiFi_Radiator_Beam.stl
https://github.com/ISS-Mimic/Mimic/blob/main/3D_Printing/HRS_Radiator_Wing/HiFi_Scissor_Beam.stl
https://github.com/ISS-Mimic/Mimic/blob/main/3D_Printing/HRS_Radiator_Wing/README.md
https://github.com/ISS-Mimic/Mimic/blob/main/3D_Printing/IPA_Roll_Out_Solar_Arrays/HiFi_IROSA_Set.stl
https://github.com/ISS-Mimic/Mimic/blob/main/3D_Printing/IPA_Roll_Out_Solar_Arrays/README.md
https://github.com/ISS-Mimic/Mimic/blob/main/3D_Printing/JEM_EF/HiFi_JEM_Bottom_Box_x4.stl
https://github.com/ISS-Mimic/Mimic/blob/main/3D_Printing/JEM_EF/HiFi_JEM_EF.stl
https://github.com/ISS-Mimic/Mimic/blob/main/3D_Printing/JEM_EF/HiFi_JEM_EFU_Boxy.stl
https://github.com/ISS-Mimic/Mimic/blob/main/3D_Printing/JEM_EF/HiFi_JEM_EFU_Comms.stl
https://github.com/ISS-Mimic/Mimic/blob/main/3D_Printing/JEM_EF/HiFi_JEM_EFU_Launcher.stl
https://github.com/ISS-Mimic/Mimic/blob/main/3D_Printing/JEM_EF/HiFi_JEM_EFU_Rampy.stl
https://github.com/ISS-Mimic/Mimic/blob/main/3D_Printing/JEM_EF/README.md
https://github.com/ISS-Mimic/Mimic/blob/main/3D_Printing/JEM_ELM_PS/HiFi_JEM_JLP.stl
https://github.com/ISS-Mimic/Mimic/blob/main/3D_Printing/JEM_ELM_PS/README.md
https://github.com/ISS-Mimic/Mimic/blob/main/3D_Printing/JEM_Kibo/HiFi_JEM.stl
https://github.com/ISS-Mimic/Mimic/blob/main/3D_Printing/JEM_Kibo/README.md
https://github.com/ISS-Mimic/Mimic/blob/main/3D_Printing/LoFi_Mimic.zip
https://github.com/ISS-Mimic/Mimic/blob/main/3D_Printing/MLM_Nauka/HiFi_MLM.stl
https://github.com/ISS-Mimic/Mimic/blob/main/3D_Printing/MLM_Nauka/HiFi_MLM_Arrays.stl
https://github.com/ISS-Mimic/Mimic/blob/main/3D_Printing/MLM_Nauka/HiFi_MLM_Radiator.stl
https://github.com/ISS-Mimic/Mimic/blob/main/3D_Printing/MLM_Nauka/LoFi-MLM-Airlock-Hatch.stl
https://github.com/ISS-Mimic/Mimic/blob/main/3D_Printing/MLM_Nauka/LoFi-MLM-Airlock.stl
https://github.com/ISS-Mimic/Mimic/blob/main/3D_Printing/MLM_Nauka/README.md
https://github.com/ISS-Mimic/Mimic/blob/main/3D_Printing/MRM_1_Rassvet/LoFi_MRM1.stl
https://github.com/ISS-Mimic/Mimic/blob/main/3D_Printing/MRM_1_Rassvet/README.md
https://github.com/ISS-Mimic/Mimic/blob/main/3D_Printing/MRM_2_Poisk/README.md
https://github.com/ISS-Mimic/Mimic/blob/main/3D_Printing/Mimic_Structural_Compoments/HDMI_PCB_Mount.stl
https://github.com/ISS-Mimic/Mimic/blob/main/3D_Printing/Mimic_Structural_Compoments/LoFi_2020-endcap-tall.stl
https://github.com/ISS-Mimic/Mimic/blob/main/3D_Printing/Mimic_Structural_Compoments/LoFi_Outboard-Truss-support.stl
https://github.com/ISS-Mimic/Mimic/blob/main/3D_Printing/Mimic_Structural_Compoments/Microcontroller_Mount_for_BGA_Controller.stl
https://github.com/ISS-Mimic/Mimic/blob/main/3D_Printing/Mimic_Structural_Compoments/Microcontroller_Mount_for_LED_Controller.stl
https://github.com/ISS-Mimic/Mimic/blob/main/3D_Printing/Mimic_Structural_Compoments/Microcontroller_Mount_for_SARJ_TRRJ_Controller.stl
https://github.com/ISS-Mimic/Mimic/blob/main/3D_Printing/Mimic_Structural_Compoments/Outboard_Truss_Interface.stl
https://github.com/ISS-Mimic/Mimic/blob/main/3D_Printing/Mimic_Structural_Compoments/README.md
https://github.com/ISS-Mimic/Mimic/blob/main/3D_Printing/Mimic_Structural_Compoments/Sabrent_USB_Hub_Mount.stl
https://github.com/ISS-Mimic/Mimic/blob/main/3D_Printing/NRAL_Nanoracks_Airlock_Bishop/HiFi_NRAL.stl
https://github.com/ISS-Mimic/Mimic/blob/main/3D_Printing/NRAL_Nanoracks_Airlock_Bishop/README.md
https://github.com/ISS-Mimic/Mimic/blob/main/3D_Printing/Node_1_Unity/HiFi_Node1_wPMA1.stl
https://github.com/ISS-Mimic/Mimic/blob/main/3D_Printing/Node_1_Unity/README.md
https://github.com/ISS-Mimic/Mimic/blob/main/3D_Printing/Node_2_Harmony/HiFi_Node2.stl
https://github.com/ISS-Mimic/Mimic/blob/main/3D_Printing/Node_2_Harmony/README.md
https://github.com/ISS-Mimic/Mimic/blob/main/3D_Printing/Node_3_Tranquility/HiFi_Node3.stl
https://github.com/ISS-Mimic/Mimic/blob/main/3D_Printing/Node_3_Tranquility/README.md
https://github.com/ISS-Mimic/Mimic/blob/main/3D_Printing/PMA/HiFi_PMA_wIDA.stl
https://github.com/ISS-Mimic/Mimic/blob/main/3D_Printing/PMA/README.md
https://github.com/ISS-Mimic/Mimic/blob/main/3D_Printing/PMM/HiFi_PMM.stl
https://github.com/ISS-Mimic/Mimic/blob/main/3D_Printing/PMM/README.md
https://github.com/ISS-Mimic/Mimic/blob/main/3D_Printing/PV_Radiator/HiFi_PVR.stl
https://github.com/ISS-Mimic/Mimic/blob/main/3D_Printing/PV_Radiator/HiFi_PVR_P4.stl
https://github.com/ISS-Mimic/Mimic/blob/main/3D_Printing/PV_Radiator/README.md
https://github.com/ISS-Mimic/Mimic/blob/main/3D_Printing/RS_Node_Prichal/HiFi_RS_Node.stl
https://github.com/ISS-Mimic/Mimic/blob/main/3D_Printing/RS_Node_Prichal/README.md
https://github.com/ISS-Mimic/Mimic/blob/main/3D_Printing/SM_Zvezda/HiFi_SM_Arrays.stl
https://github.com/ISS-Mimic/Mimic/blob/main/3D_Printing/SM_Zvezda/LoFi_ServiceModule-ant-boom.stl
https://github.com/ISS-Mimic/Mimic/blob/main/3D_Printing/SM_Zvezda/LoFi_ServiceModule-ant-dish.stl
https://github.com/ISS-Mimic/Mimic/blob/main/3D_Printing/SM_Zvezda/LoFi_Zvezda.stl
https://github.com/ISS-Mimic/Mimic/blob/main/3D_Printing/SM_Zvezda/LoFi_Zvezda_End.stl
https://github.com/ISS-Mimic/Mimic/blob/main/3D_Printing/SM_Zvezda/README.md
https://github.com/ISS-Mimic/Mimic/blob/main/3D_Printing/SSRMS_Canadarm_and_MT_MBS/HiFi_SSRMS.stl
https://github.com/ISS-Mimic/Mimic/blob/main/3D_Printing/SSRMS_Canadarm_and_MT_MBS/LoFi_MobileBaseSystem_Base.stl
https://github.com/ISS-Mimic/Mimic/blob/main/3D_Printing/SSRMS_Canadarm_and_MT_MBS/LoFi_MobileBaseSystem_Body.stl
https://github.com/ISS-Mimic/Mimic/blob/main/3D_Printing/SSRMS_Canadarm_and_MT_MBS/README.md
https://github.com/ISS-Mimic/Mimic/blob/main/3D_Printing/Solar_Array_Wing/Fat_Mast_Solid_Core_Solar_Array_Wing.stl
https://github.com/ISS-Mimic/Mimic/blob/main/3D_Printing/Solar_Array_Wing/HiFi_Solar_Array_Wing.step
https://github.com/ISS-Mimic/Mimic/blob/main/3D_Printing/Solar_Array_Wing/HiFi_Solar_Array_Wing.stl
https://github.com/ISS-Mimic/Mimic/blob/main/3D_Printing/Solar_Array_Wing/LoFi_Solar_Array_Wing.stl
https://github.com/ISS-Mimic/Mimic/blob/main/3D_Printing/Solar_Array_Wing/README.md
https://github.com/ISS-Mimic/Mimic/blob/main/3D_Printing/Solar_Array_Wing/Solid_Core_Solar_Array_Wing.stl
https://github.com/ISS-Mimic/Mimic/blob/main/3D_Printing/Truss_P1/LoFi_ITS-P1.stl
https://github.com/ISS-Mimic/Mimic/blob/main/3D_Printing/Truss_P1/README.md
https://github.com/ISS-Mimic/Mimic/blob/main/3D_Printing/Truss_P3/LoFi-ITS-P3-complex.stl
https://github.com/ISS-Mimic/Mimic/blob/main/3D_Printing/Truss_P3/README.md
https://github.com/ISS-Mimic/Mimic/blob/main/3D_Printing/Truss_P6/CCR10_HiFi_Truss_P6.3mf
https://github.com/ISS-Mimic/Mimic/blob/main/3D_Printing/Truss_P6/HiFi_Truss_P6.stl
https://github.com/ISS-Mimic/Mimic/blob/main/3D_Printing/Truss_P6/HiFi_Truss_P6_PFCS.stl
https://github.com/ISS-Mimic/Mimic/blob/main/3D_Printing/Truss_P6/HiFi_Truss_P6_STCR.stl
https://github.com/ISS-Mimic/Mimic/blob/main/3D_Printing/Truss_P6/HiFi_Truss_P6_TTCR.stl
https://github.com/ISS-Mimic/Mimic/blob/main/3D_Printing/Truss_P6/README.md
https://github.com/ISS-Mimic/Mimic/blob/main/3D_Printing/Truss_S0/LoFi_ITS-S0-Destiny_Connector.stl
https://github.com/ISS-Mimic/Mimic/blob/main/3D_Printing/Truss_S0/LoFi_ITS-S0.stl
https://github.com/ISS-Mimic/Mimic/blob/main/3D_Printing/Truss_S0/LoFi_S0-093018.stl
https://github.com/ISS-Mimic/Mimic/blob/main/3D_Printing/Truss_S0/MiFi_ITS_S0.stl
https://github.com/ISS-Mimic/Mimic/blob/main/3D_Printing/Truss_S0/README.md
https://github.com/ISS-Mimic/Mimic/blob/main/3D_Printing/Truss_S1/LoFi_ITS-1_AmmoniaTank.stl
https://github.com/ISS-Mimic/Mimic/blob/main/3D_Printing/Truss_S1/LoFi_ITS-1_Mounts (1).stl
https://github.com/ISS-Mimic/Mimic/blob/main/3D_Printing/Truss_S1/LoFi_ITS-1_TRRJ-Beam.stl
https://github.com/ISS-Mimic/Mimic/blob/main/3D_Printing/Truss_S1/LoFi_ITS-S1_.stl
https://github.com/ISS-Mimic/Mimic/blob/main/3D_Printing/Truss_S1/README.md
https://github.com/ISS-Mimic/Mimic/blob/main/3D_Printing/Truss_S3/LoFi_ITS-3_SARJ_Gear_Ring.stl
https://github.com/ISS-Mimic/Mimic/blob/main/3D_Printing/Truss_S3/LoFi_ITS-S3-complex.stl
https://github.com/ISS-Mimic/Mimic/blob/main/3D_Printing/Truss_S3/README.md
https://github.com/ISS-Mimic/Mimic/blob/main/3D_Printing/Truss_S4_S5_P4_P5/HiFi_Truss_PS45.stl
https://github.com/ISS-Mimic/Mimic/blob/main/3D_Printing/Truss_S4_S5_P4_P5/LoFi_ITS-4_5-complex.stl
https://github.com/ISS-Mimic/Mimic/blob/main/3D_Printing/Truss_S4_S5_P4_P5/LoFi_ITS-4_5-simple.stl
https://github.com/ISS-Mimic/Mimic/blob/main/3D_Printing/Truss_S4_S5_P4_P5/LoFi_ITS-4_SARJ_Connector.stl
https://github.com/ISS-Mimic/Mimic/blob/main/3D_Printing/Truss_S4_S5_P4_P5/LoFi_OutboardRadiatorBase.stl
https://github.com/ISS-Mimic/Mimic/blob/main/3D_Printing/Truss_S4_S5_P4_P5/README.md
https://github.com/ISS-Mimic/Mimic/blob/main/3D_Printing/Truss_S6/HiFi_Truss_S6.stl
https://github.com/ISS-Mimic/Mimic/blob/main/3D_Printing/Truss_S6/LoFi_ITS-6-simple.stl
https://github.com/ISS-Mimic/Mimic/blob/main/3D_Printing/Truss_S6/LoFi_ITS-6_IEA-complex.stl
https://github.com/ISS-Mimic/Mimic/blob/main/3D_Printing/Truss_S6/LoFi_ITS-6_LS-complex.stl
https://github.com/ISS-Mimic/Mimic/blob/main/3D_Printing/Truss_S6/README.md
https://github.com/ISS-Mimic/Mimic/blob/main/3D_Printing/Truss_Z1/HiFi_Truss_Z1_Bottom.stl
https://github.com/ISS-Mimic/Mimic/blob/main/3D_Printing/Truss_Z1/HiFi_Truss_Z1_SASA.stl
https://github.com/ISS-Mimic/Mimic/blob/main/3D_Printing/Truss_Z1/HiFi_Truss_Z1_Scuff_Plate.stl
https://github.com/ISS-Mimic/Mimic/blob/main/3D_Printing/Truss_Z1/HiFi_Truss_Z1_Top.stl
https://github.com/ISS-Mimic/Mimic/blob/main/3D_Printing/Truss_Z1/HiFi_Truss_Z1_Tray.stl
https://github.com/ISS-Mimic/Mimic/blob/main/3D_Printing/Truss_Z1/MidFi_Truss_Z1.stl
https://github.com/ISS-Mimic/Mimic/blob/main/3D_Printing/Truss_Z1/README.md
https://github.com/ISS-Mimic/Mimic/blob/main/3D_Printing/US_Airlock_Quest/HiFi_US_Airlock.stl
https://github.com/ISS-Mimic/Mimic/blob/main/3D_Printing/US_Airlock_Quest/README.md
https://github.com/ISS-Mimic/Mimic/blob/main/3D_Printing/US_Lab_Destiny/HiFi-DestinyLab-1.stl
https://github.com/ISS-Mimic/Mimic/blob/main/3D_Printing/US_Lab_Destiny/HiFi-DestinyLab-2.stl
https://github.com/ISS-Mimic/Mimic/blob/main/3D_Printing/US_Lab_Destiny/HiFi-DestinyLab-ETVCG.stl
https://github.com/ISS-Mimic/Mimic/blob/main/3D_Printing/US_Lab_Destiny/HiFi-DestinyLab-SBAND.stl
https://github.com/ISS-Mimic/Mimic/blob/main/3D_Printing/US_Lab_Destiny/HiFi-DestinyLab-Stanchion.stl
https://github.com/ISS-Mimic/Mimic/blob/main/3D_Printing/US_Lab_Destiny/HiFi-DestinyLab-WORF.stl
https://github.com/ISS-Mimic/Mimic/blob/main/3D_Printing/US_Lab_Destiny/README.md
https://github.com/ISS-Mimic/Mimic/blob/main/3D_Printing/Visiting_Vehicles/Crew_Dragon/HiFi_Dragon.stl
https://github.com/ISS-Mimic/Mimic/blob/main/3D_Printing/Visiting_Vehicles/Crew_Dragon/README.md
https://github.com/ISS-Mimic/Mimic/blob/main/3D_Printing/Visiting_Vehicles/Cygnus/HiFi_Cygnus.stl
https://github.com/ISS-Mimic/Mimic/blob/main/3D_Printing/Visiting_Vehicles/Cygnus/README.md
https://github.com/ISS-Mimic/Mimic/blob/main/3D_Printing/Visiting_Vehicles/Dream_Chaser/HiFi_Dream_Chaser.stl
https://github.com/ISS-Mimic/Mimic/blob/main/3D_Printing/Visiting_Vehicles/Dream_Chaser/HiFi_Shooting_Star_Module.stl
https://github.com/ISS-Mimic/Mimic/blob/main/3D_Printing/Visiting_Vehicles/Dream_Chaser/HiFi_Shooting_Star_Solar_Array_2x.stl
https://github.com/ISS-Mimic/Mimic/blob/main/3D_Printing/Visiting_Vehicles/Dream_Chaser/README.md
https://github.com/ISS-Mimic/Mimic/blob/main/3D_Printing/Visiting_Vehicles/HTV/HiFi_HTV.stl
https://github.com/ISS-Mimic/Mimic/blob/main/3D_Printing/Visiting_Vehicles/HTV/HiFi_HTV_EP.stl
https://github.com/ISS-Mimic/Mimic/blob/main/3D_Printing/Visiting_Vehicles/HTV/README.md
https://github.com/ISS-Mimic/Mimic/blob/main/3D_Printing/Visiting_Vehicles/Progress/HiFi_Progress.stl
https://github.com/ISS-Mimic/Mimic/blob/main/3D_Printing/Visiting_Vehicles/Progress/HiFi_Soyuz_Solar_Arrays.stl
https://github.com/ISS-Mimic/Mimic/blob/main/3D_Printing/Visiting_Vehicles/Progress/README.md
https://github.com/ISS-Mimic/Mimic/blob/main/3D_Printing/Visiting_Vehicles/README.md
https://github.com/ISS-Mimic/Mimic/blob/main/3D_Printing/Visiting_Vehicles/Soyuz/HiFi_Soyuz.stl
https://github.com/ISS-Mimic/Mimic/blob/main/3D_Printing/Visiting_Vehicles/Soyuz/HiFi_Soyuz_Solar_Arrays.stl
https://github.com/ISS-Mimic/Mimic/blob/main/3D_Printing/Visiting_Vehicles/Soyuz/README.md
https://github.com/ISS-Mimic/Mimic/blob/main/3D_Printing/Visiting_Vehicles/Starliner/ATTRIBUTION.txt
https://github.com/ISS-Mimic/Mimic/blob/main/3D_Printing/Visiting_Vehicles/Starliner/HiFi_CST100_Starliner.stl
https://github.com/ISS-Mimic/Mimic/blob/main/3D_Printing/Visiting_Vehicles/Starliner/README.md
https://github.com/ISS-Mimic/Mimic/blob/main/3D_Printing/archive_lofi/Cupola-Body.stl
https://github.com/ISS-Mimic/Mimic/blob/main/3D_Printing/archive_lofi/Cupola-SideWindow.stl
https://github.com/ISS-Mimic/Mimic/blob/main/3D_Printing/archive_lofi/Cupola-TopWindow.stl
https://github.com/ISS-Mimic/Mimic/blob/main/3D_Printing/archive_lofi/DC_1_Pirs/LoFi_DockingCompartment.stl
https://github.com/ISS-Mimic/Mimic/blob/main/3D_Printing/archive_lofi/DC_1_Pirs/README.md
https://github.com/ISS-Mimic/Mimic/blob/main/3D_Printing/archive_lofi/HiFi_PMA2.stl
https://github.com/ISS-Mimic/Mimic/blob/main/3D_Printing/archive_lofi/HiFi_PVR_ScissorBeam_1x.stl
https://github.com/ISS-Mimic/Mimic/blob/main/3D_Printing/archive_lofi/IDA/LoFi_IDA23.stl
https://github.com/ISS-Mimic/Mimic/blob/main/3D_Printing/archive_lofi/IDA/README.md
https://github.com/ISS-Mimic/Mimic/blob/main/3D_Printing/archive_lofi/LoFi-ITS-Z1.stl
https://github.com/ISS-Mimic/Mimic/blob/main/3D_Printing/archive_lofi/LoFi_BEAM.stl
https://github.com/ISS-Mimic/Mimic/blob/main/3D_Printing/archive_lofi/LoFi_COF-End.stl
https://github.com/ISS-Mimic/Mimic/blob/main/3D_Printing/archive_lofi/LoFi_Canadaarm2_Arm.stl
https://github.com/ISS-Mimic/Mimic/blob/main/3D_Printing/archive_lofi/LoFi_Canadaarm2_EE.stl
https://github.com/ISS-Mimic/Mimic/blob/main/3D_Printing/archive_lofi/LoFi_DestinyLab-1.stl
https://github.com/ISS-Mimic/Mimic/blob/main/3D_Printing/archive_lofi/LoFi_DestinyLab-2.stl
https://github.com/ISS-Mimic/Mimic/blob/main/3D_Printing/archive_lofi/LoFi_HarmonyNode2-1.stl
https://github.com/ISS-Mimic/Mimic/blob/main/3D_Printing/archive_lofi/LoFi_HarmonyNode2-2.stl
https://github.com/ISS-Mimic/Mimic/blob/main/3D_Printing/archive_lofi/LoFi_HarmonyNode2-3_v3a.stl
https://github.com/ISS-Mimic/Mimic/blob/main/3D_Printing/archive_lofi/LoFi_HarmonyNode2-3_v3b.stl
https://github.com/ISS-Mimic/Mimic/blob/main/3D_Printing/archive_lofi/LoFi_JEM-ELM-magnet_093018.stl
https://github.com/ISS-Mimic/Mimic/blob/main/3D_Printing/archive_lofi/LoFi_JEM-PM-magnet_093018.stl
https://github.com/ISS-Mimic/Mimic/blob/main/3D_Printing/archive_lofi/LoFi_JEM-PM.stl
https://github.com/ISS-Mimic/Mimic/blob/main/3D_Printing/archive_lofi/LoFi_JEM-PS.stl
https://github.com/ISS-Mimic/Mimic/blob/main/3D_Printing/archive_lofi/LoFi_LEO-COF-barrel.stl
https://github.com/ISS-Mimic/Mimic/blob/main/3D_Printing/archive_lofi/LoFi_Leonardo_End.stl
https://github.com/ISS-Mimic/Mimic/blob/main/3D_Printing/archive_lofi/LoFi_PMA123.stl
https://github.com/ISS-Mimic/Mimic/blob/main/3D_Printing/archive_lofi/LoFi_UnityNode1-1.stl
https://github.com/ISS-Mimic/Mimic/blob/main/3D_Printing/archive_lofi/LoFi_UnityNode1-2.stl
https://github.com/ISS-Mimic/Mimic/blob/main/3D_Printing/archive_lofi/LoFi_UnityNode1-v2a.stl
https://github.com/ISS-Mimic/Mimic/blob/main/3D_Printing/archive_lofi/LoFi_UnityNode1-v2b.stl
https://github.com/ISS-Mimic/Mimic/blob/main/3D_Printing/archive_lofi/LoFi_Zarya.stl
https://github.com/ISS-Mimic/Mimic/blob/main/3D_Printing/archive_lofi/LoFi_node2-3-magnet-barrel_093018.stl
https://github.com/ISS-Mimic/Mimic/blob/main/3D_Printing/archive_lofi/LoFi_node2-3-magnet-endcap_093018.stl
https://github.com/ISS-Mimic/Mimic/blob/main/3D_Printing/archive_lofi/README.md
https://github.com/ISS-Mimic/Mimic/blob/main/3D_Printing/archive_lofi/starliner_cm.stl
https://github.com/ISS-Mimic/Mimic/blob/main/3D_Printing/archive_lofi/starliner_sm.stl
https://github.com/ISS-Mimic/Mimic/blob/main/3D_Printing/archive_lofi/starliner_umbilical.stl
https://github.com/ISS-Mimic/Mimic/blob/main/3D_Printing/file_list.txt

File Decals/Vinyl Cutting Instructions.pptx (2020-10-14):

## Vinyl Cutting

ISS solar cells

Chen Deng
Raindrop8888@gmail.com
440-382-3839 (cell)

## Goal

Quantity needed: 24 panels. 5 panels per sheet, therefore need 5 cuts
Size setting: 32 cm x 4.5 cm

32 cm

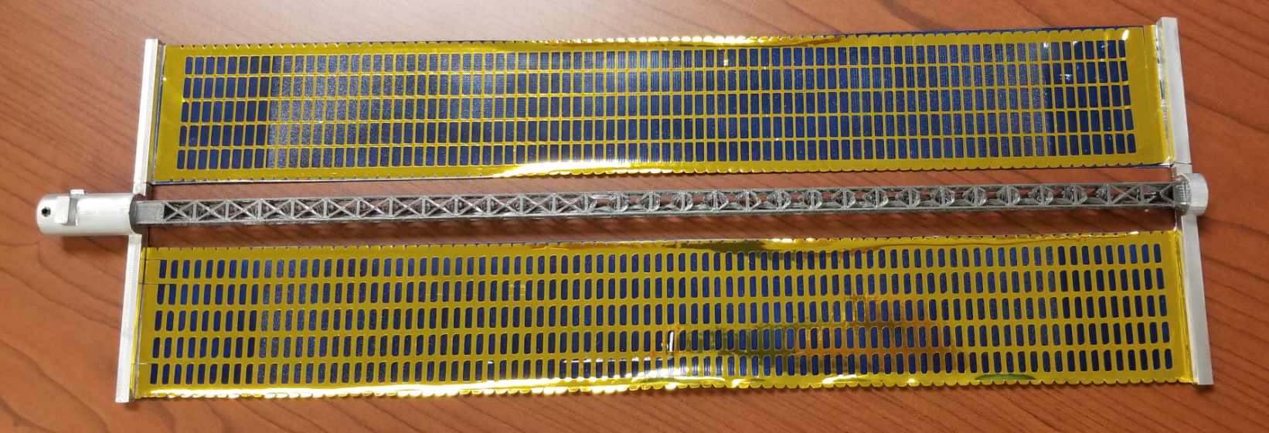
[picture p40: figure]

4.5 cm

## File -> import

(If import image doesn't have the nice lacy edges, see lessons learned page below)

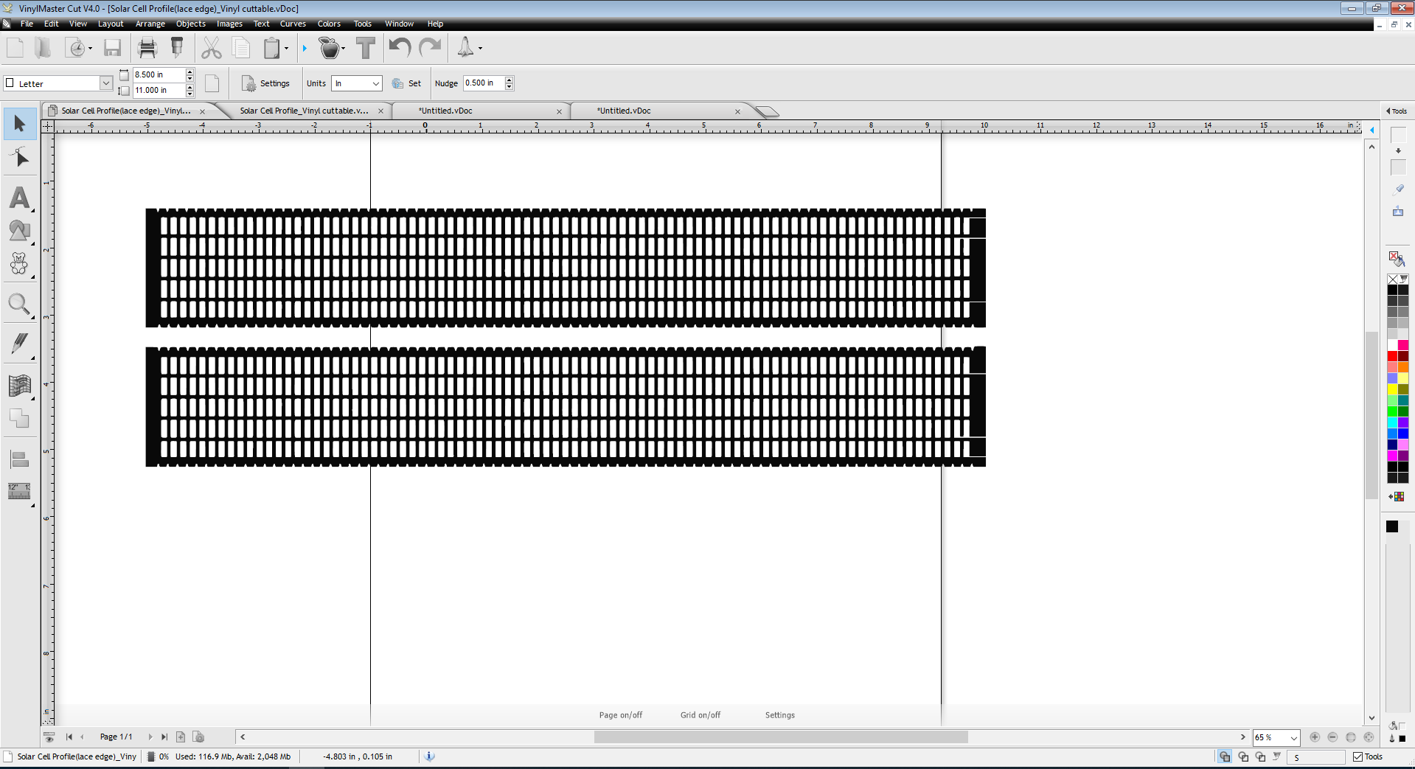
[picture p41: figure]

## Cut icon

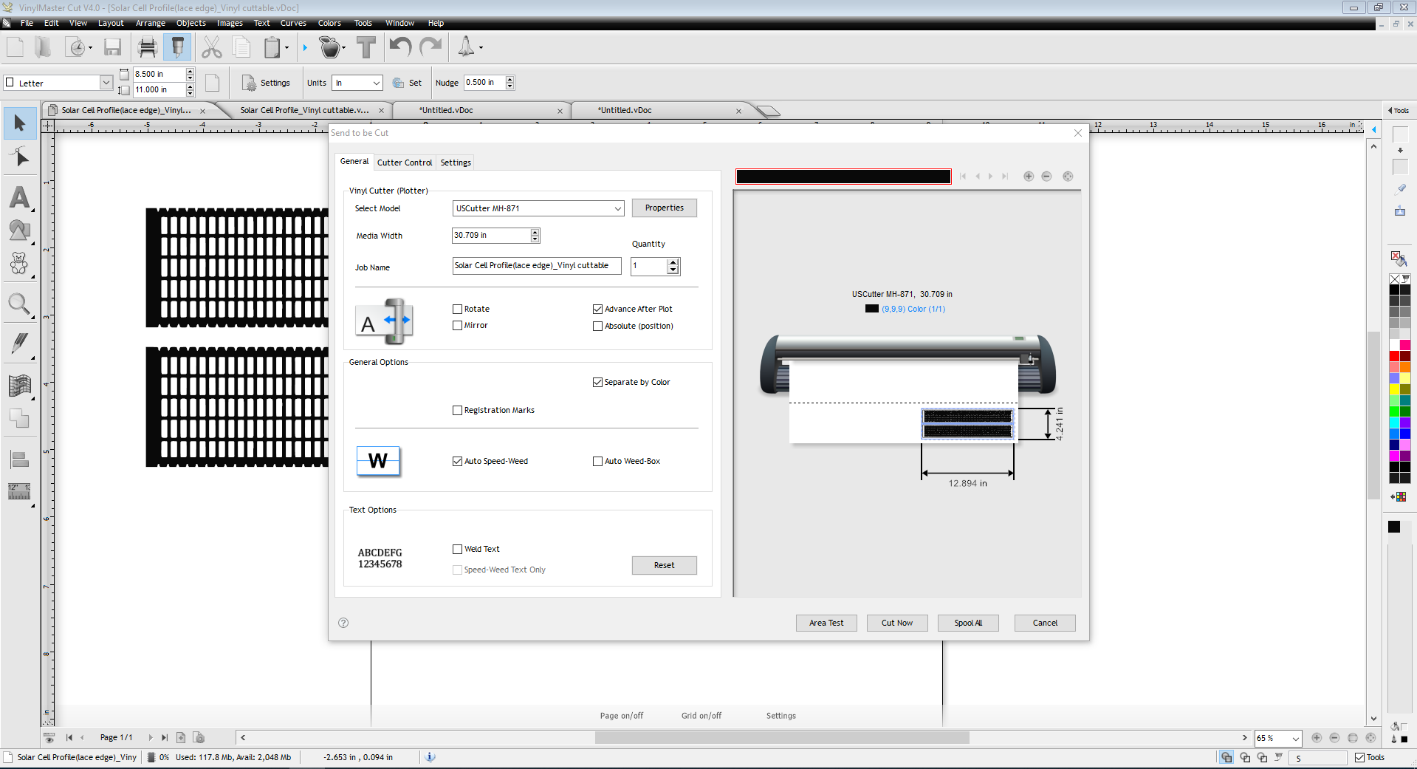
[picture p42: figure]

## Area Test (This will allow cutter to show the area to be cut, to make sure vinyl is in the correct area)

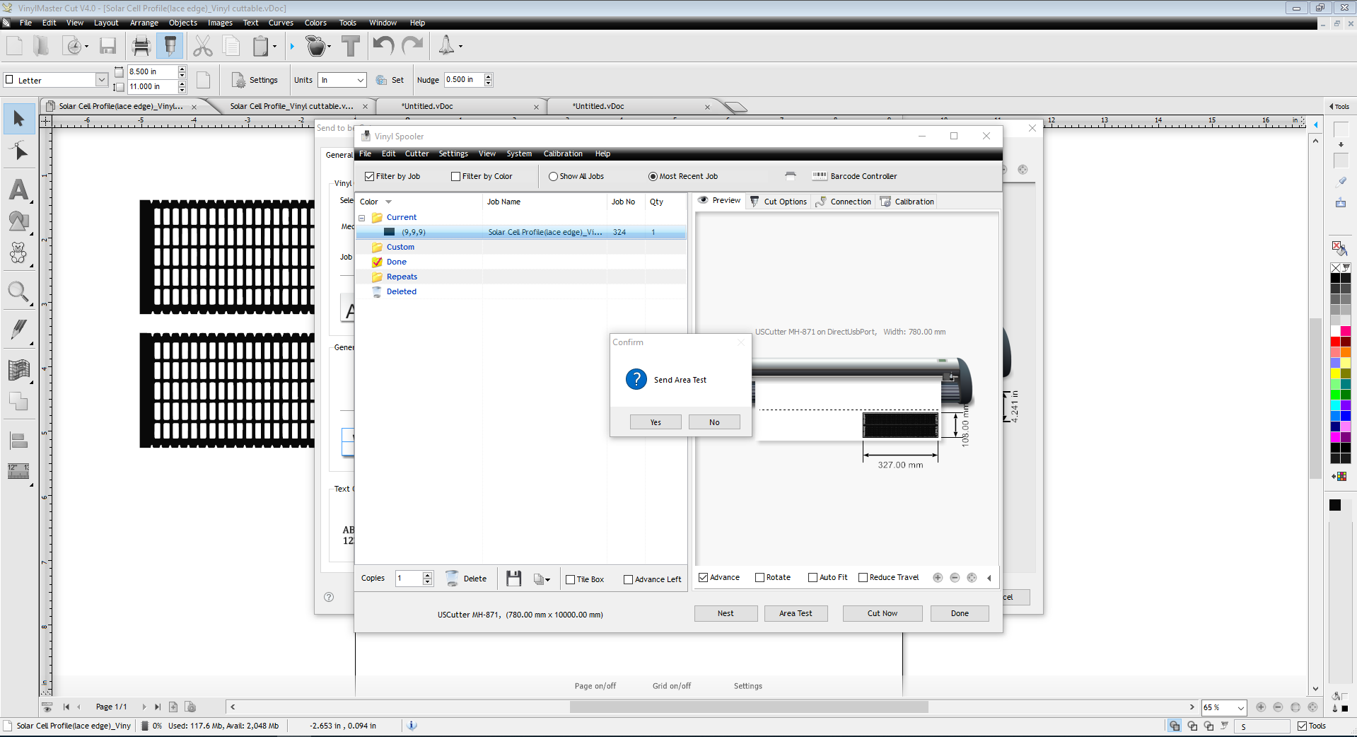
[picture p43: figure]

## Cut confirmation

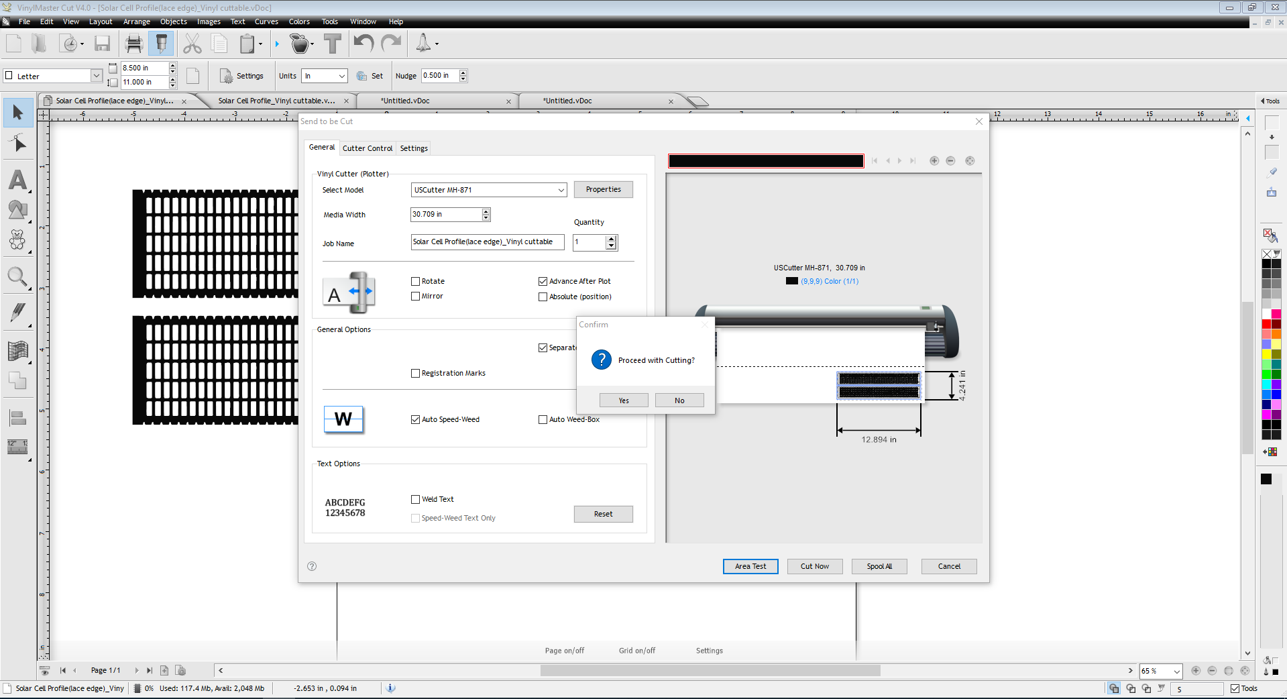
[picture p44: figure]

## Cut Now – Command to cut Vinyl

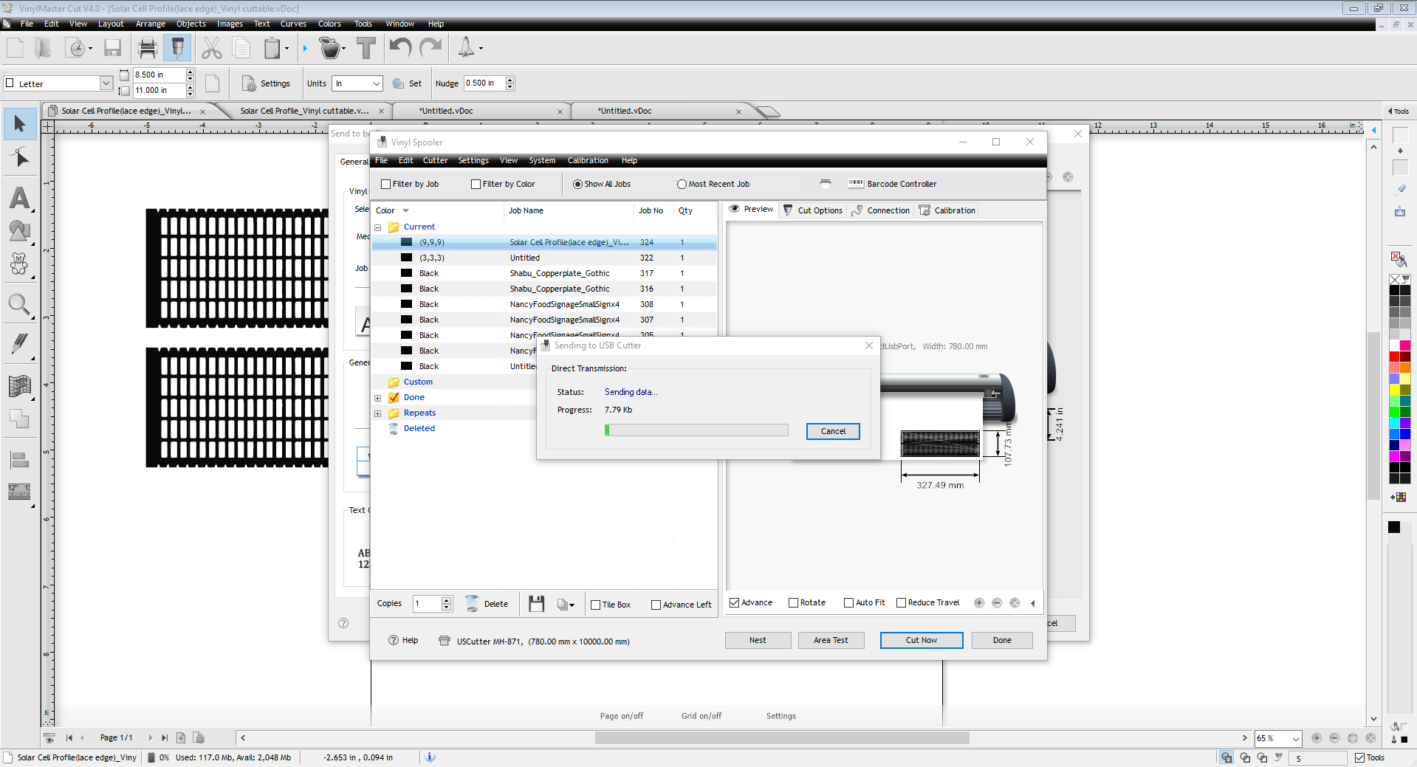
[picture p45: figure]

## Lessons Learned: Issue(s) encountered

Issue 1: SVG file did not import properly. Aka, image was did not display correctly, no lacy edges
Work around: Imported SVG to Inkscape, then export to PNG. This make a screen shot of image. Then import PNG file to VinylMast Cut V4.0
Issue 2: VinylMaster Cut V4.0 gave error (Nothing to cut)
Work around: While in VinylMaster program:
- Click “Vectorizer”
- Click “trace”
http (http://forum.uscutter.com/index.php?/topic/53598-vinylmaster-cut-trace-issue/)://forum.uscutter.com/index.php?/topic/53598-vinylmaster-cut-trace-issue/

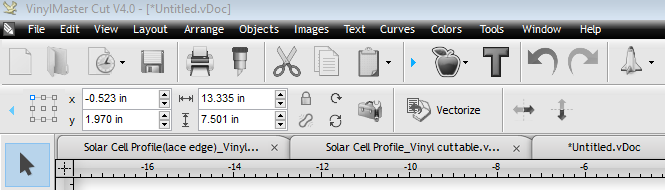
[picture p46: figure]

## What file type need for Vinyl cutting at Freeman Branch Library

- Program to used for cutting is VinylMaster Cut V4.0, which has extension of .vDoc
- Files type can be imported:
  - SVG file
  - Adobe Illustrator file
  - PNG file

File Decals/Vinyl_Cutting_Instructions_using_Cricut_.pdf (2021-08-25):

# Cutting SAW Vinyl with Cricut Maker

### Last updated: 2021.05.04 May the 4th be with you!

# What you are making

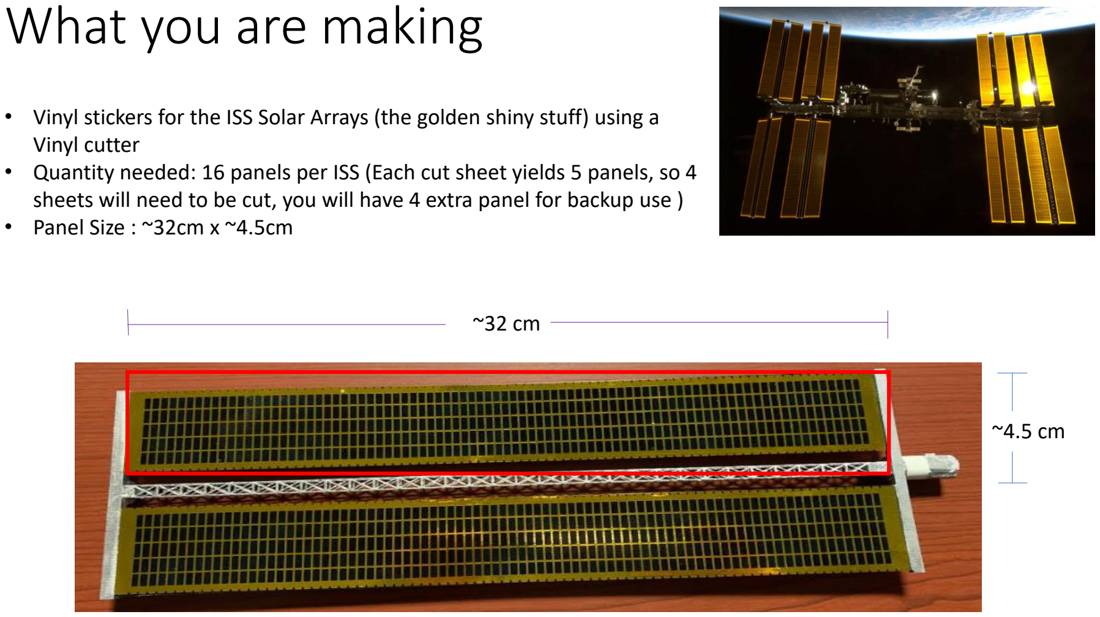
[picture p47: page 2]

- Vinyl stickers for the ISS Solar Arrays (the golden shiny stuff) using a Vinyl cutter
- Quantity needed: 16 panels per ISS (Each cut sheet yields 5 panels, so 4 sheets will need to be cut, you will have 4 extra panel for backup use )
- Panel Size : ~32cm x ~4.5cm

~32 cm

~4.5 cm

# Here is what you need

## - Cricut Maker (https://cricut.com/en_us/machines/cricut-maker.html) - Cricut Design Space (https://design.cricut.com/) v6.7.201 (used here for images)

- SAW file (https://raw.githubusercontent.com/ISS-Mimic/Mimic/master/Decals/SAW_svg_working.svg) (download from Github)

## - 3D printed & painted ISS Solar Array

- 12” x 24” Cricut mat (https://www.joann.com/cricut-cutting-mat-12inx24in-2/pkg-standardgrip/9287830.html)

## - Shiny Vinyl (https://www.amazon.com/gp/product/B07XZ3XY42/) - Transfer tape (https://www.amazon.com/Cricut-2002363-Vinyl-Transfer-Tape/dp/B00LJV1KYO)

- Embossing tool (https://www.michaels.com/embossing-stylus-tool-set-by-craft-smart/10045694.html?r=g&Kenshoo_ida=) or Weeding tool (https://www.amazon.com/Cricut-2004233-Tools-Weeding-Kit/dp/B071KMBGCR?hvadid=198059709086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)

## - Tweezers (optional, but recommended) - Scissors or Paper cutter - Patience + loads of time for weeding

1) Turn on & plug in Cricut Maker
2) On computer, launch Cricut Design Space
3) Click New Project
- Project image will be saved to My Projects for future use after initial upload (see example right)
4) Click Upload
5) Click Upload Image
6) Drag and drop ISS SAW file into window or click Browse to locate file to upload
7) Click Upload
8) Click the image/project you just uploaded under Recent Uploads
9) Click Insert Images, then image will show up on the canvas

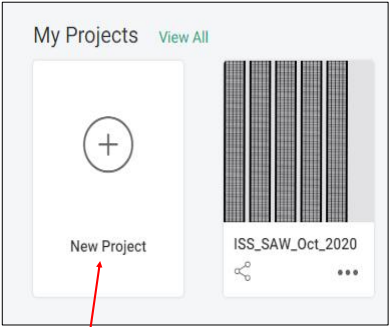
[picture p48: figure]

3

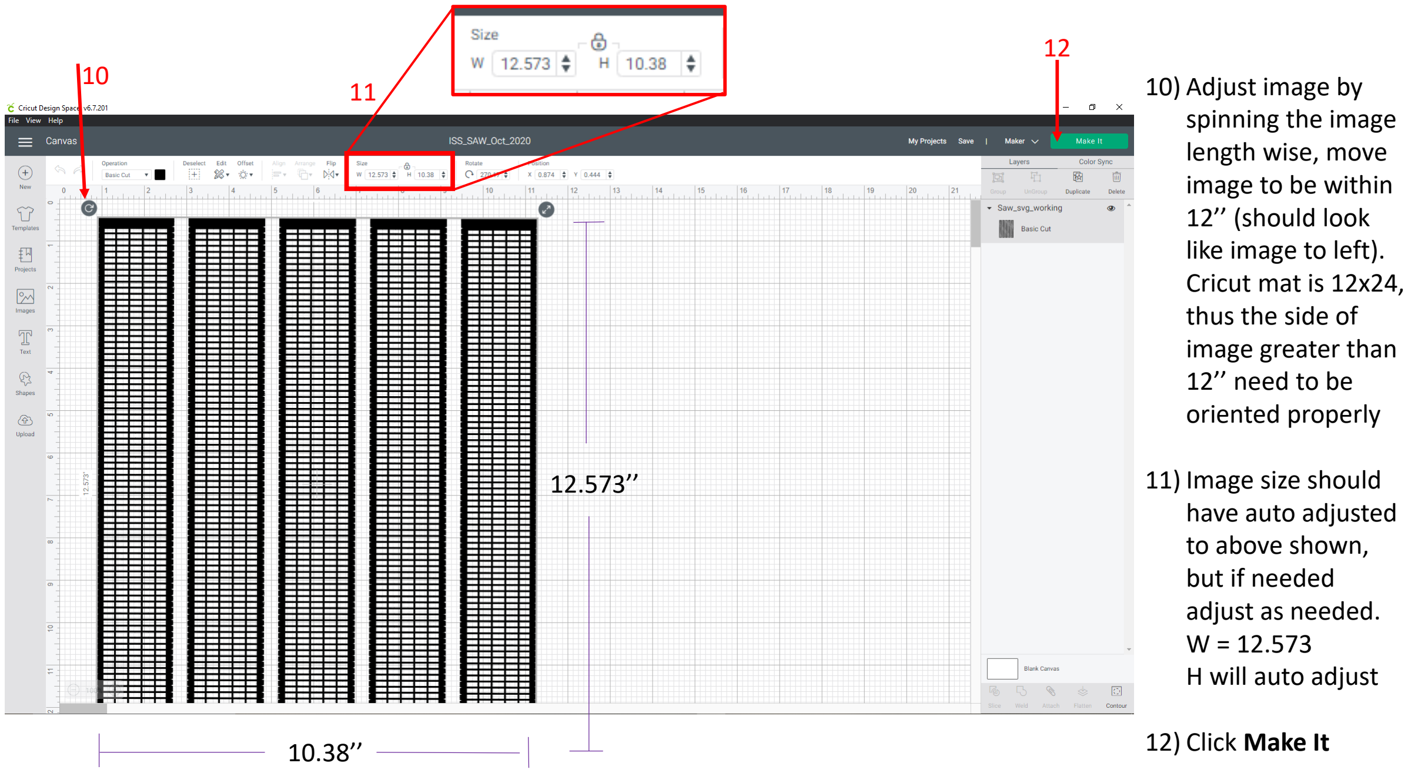
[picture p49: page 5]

10) Adjust image by
spinning the image
length wise, move
image to be within
12’’ (should look
like image to left).
Cricut mat is 12x24,
thus the side of
image greater than
12’’ need to be
oriented properly
11) Image size should
have auto adjusted
to above shown,
but if needed
adjust as needed.
W = 12.573
H will auto adjust
12) Click Make It

12.573’’

10.38’’

12
10 | 11

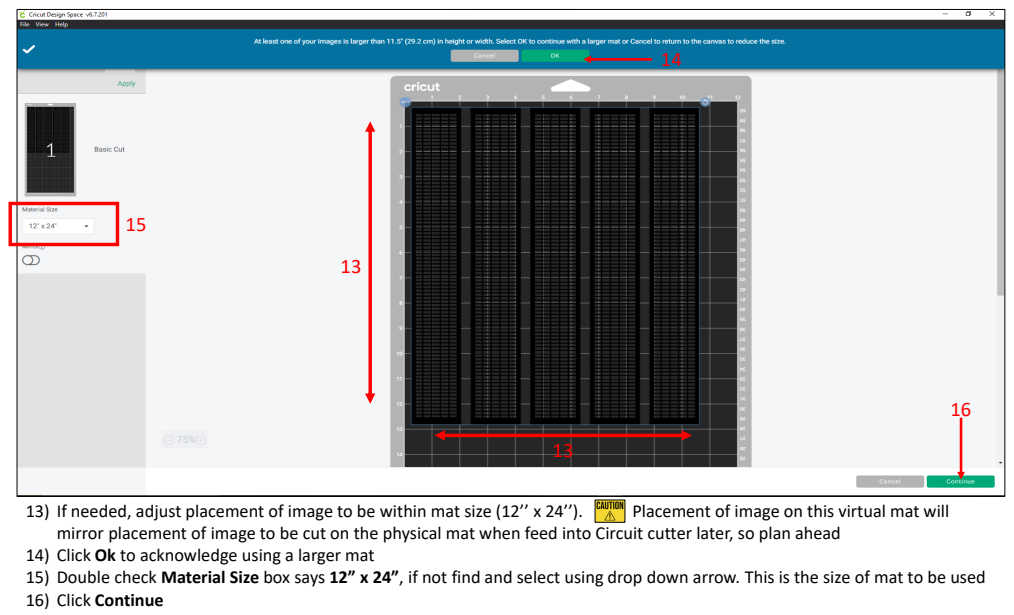
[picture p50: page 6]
13) If needed, adjust placement of image to be within mat size (12’’ x 24’’).; Placement of image on this virtual mat will

mirror placement of image to be cut on the physical mat when feed into Circuit cutter later, so plan ahead
14) Click Ok to acknowledge using a larger mat
15) Double check Material Size box says 12” x 24”, if not find and select using drop down arrow. This is the size of mat to be used
16) Click Continue

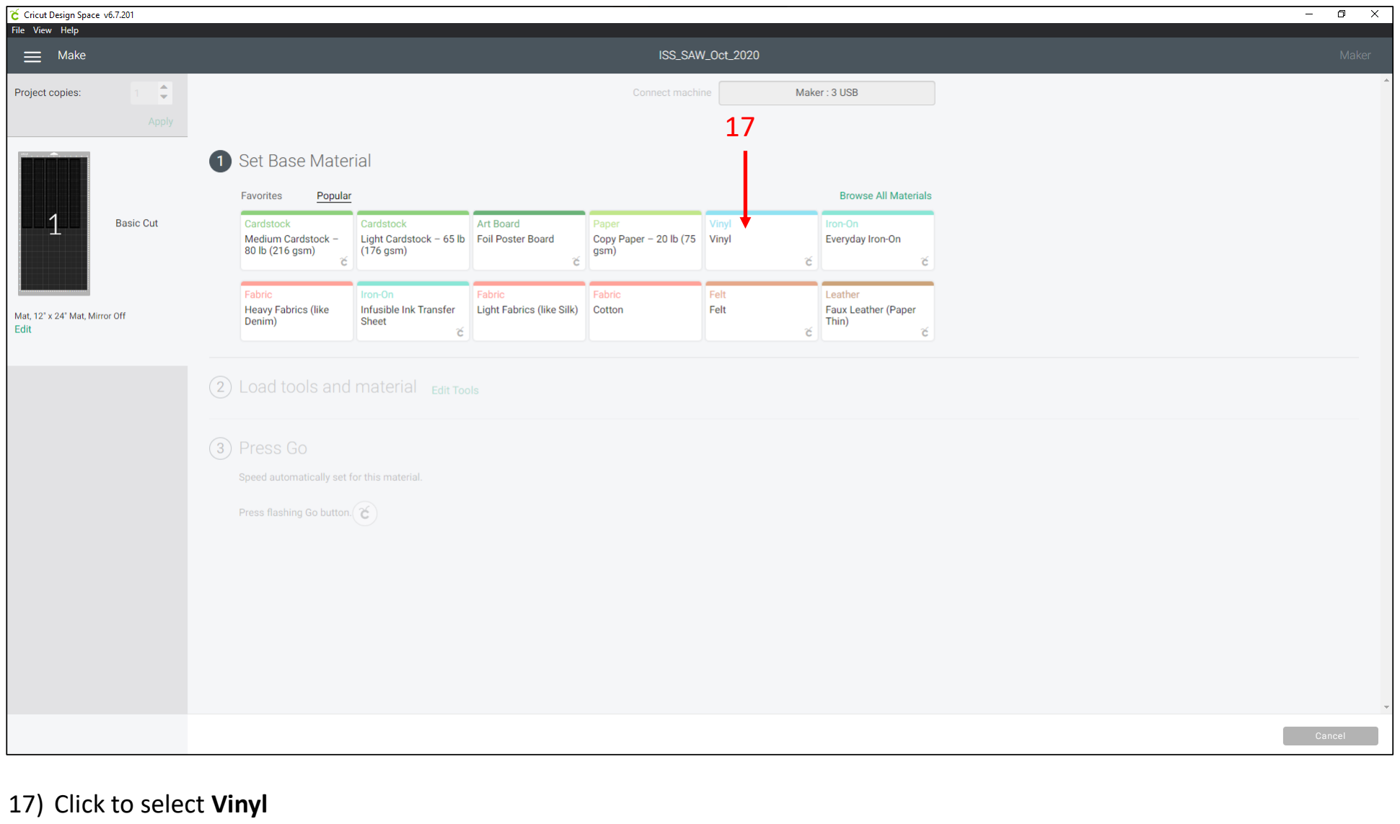
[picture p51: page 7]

17) Click to select Vinyl

17

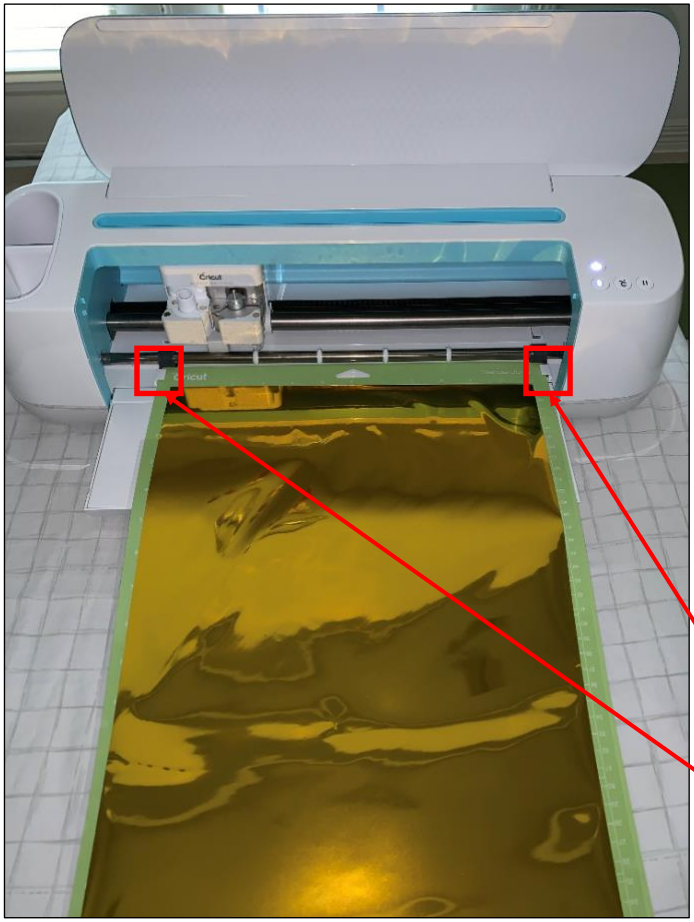
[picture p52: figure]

18) Cricut unit placement : Allow at least 24” of space between back of unit to any object, such as a wall. This is needed to accommodate the physical mat travel space as it cuts the image
19) Prep & load the Vinyl & mat:
- Remove the clear protective film from 12”x24” mat & save for later use). Place the mat on a flat surface, sticky side up
- Unroll the Vinyl sheet, with shiny side up (as shown image to left), align & place the Vinyl sheet onto sticky side of mat. Placing Vinyl sheet on mat can be tricky, easier with a second set of hands, go find a volunteer! Be sure the Vinyl sheet covers the surface area on mat shown as preview in step 13
- If needed, to adjust Vinyl placement on mat, Flip mat onto a flat surface, Vinyl side down. Carpeted floor works just fine. Secure the Vinyl with one hand flat against surface, peel mat slowly from Vinyl with the other hand (instead of Vinyl from mat, this will result in less curl up Vinyl)
- When ready, peel off clear protective film from Vinyl sheet & trash
- Load mat onto Cricut mat track

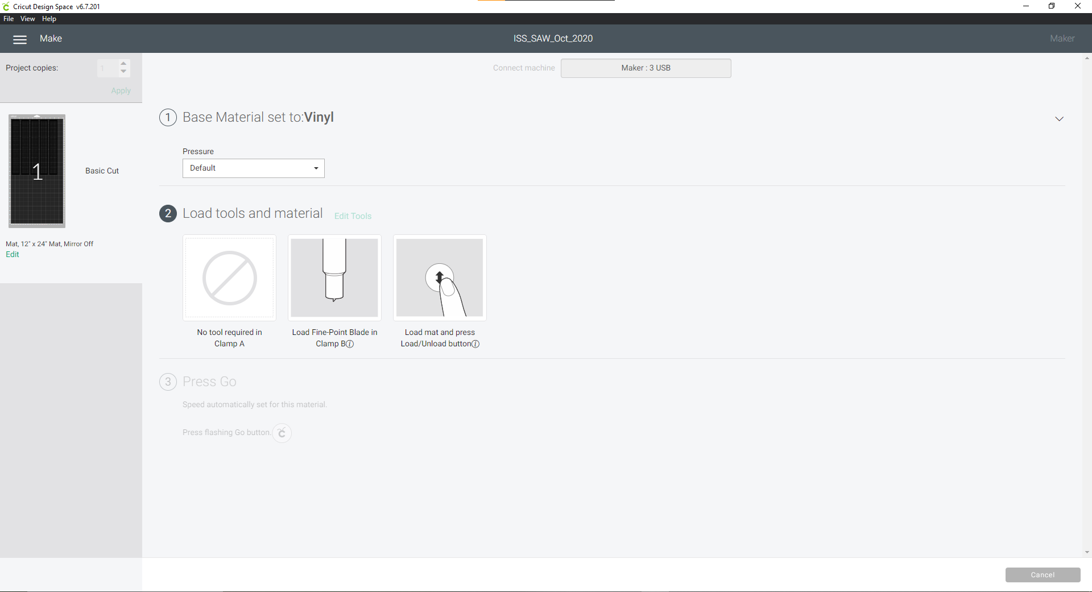
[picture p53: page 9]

20) Check to make sure Fine-Point Blade is in Clamp B. (Pre-install in unit out of box)
21) Press Load button on the Cricut unit. Button should be flashing

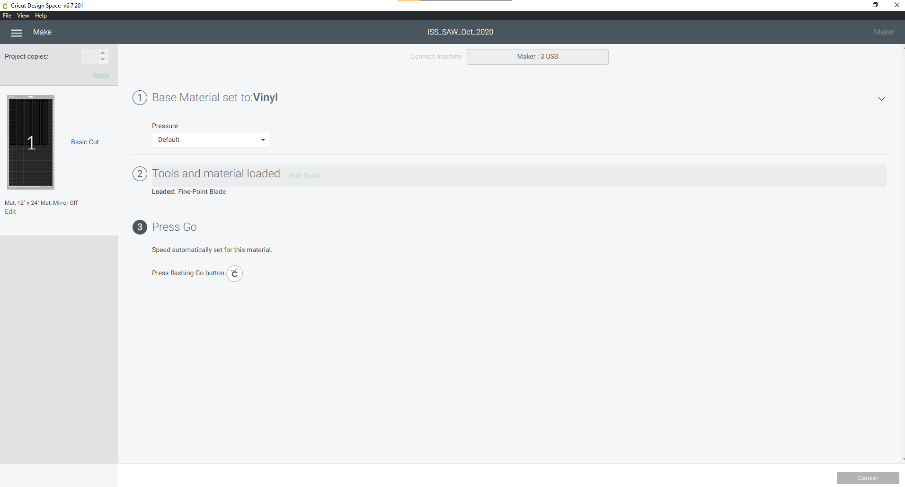
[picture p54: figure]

22) Press Go Cricut button on the Cricut unit. Button should be flashing

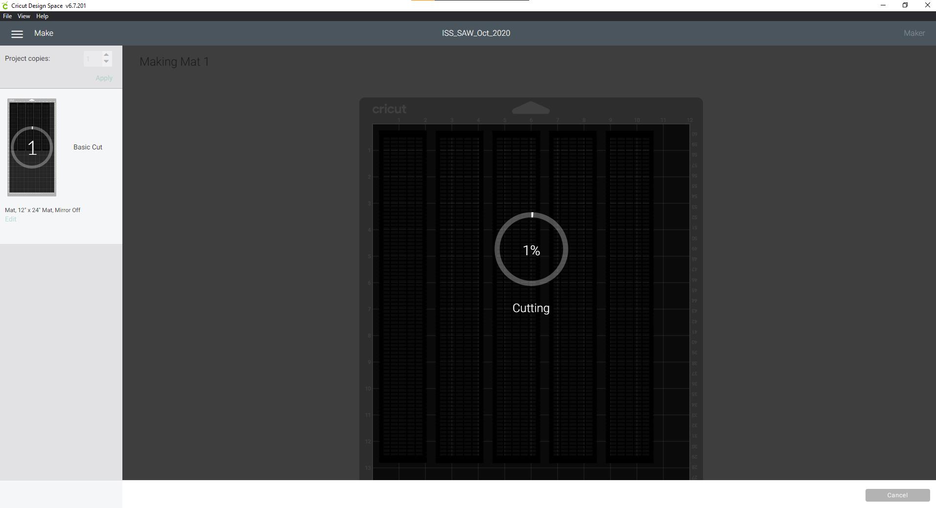
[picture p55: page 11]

23) Sit back and enjoy the cutting show. Take some time to stretch your fingers in readiness for weeding later ;-)

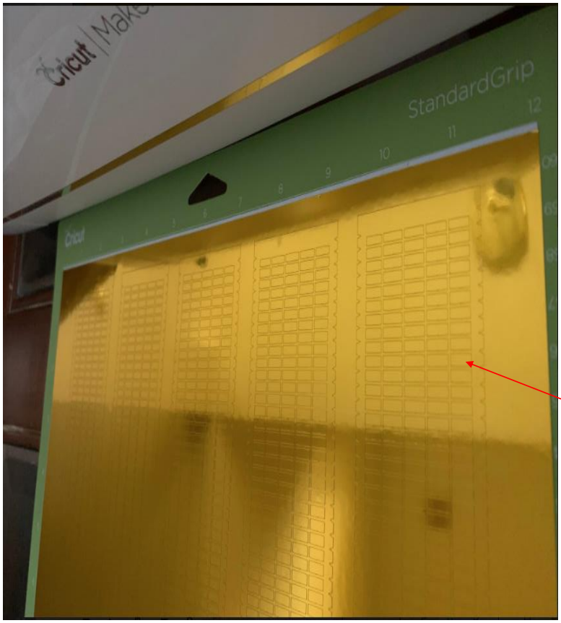
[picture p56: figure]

24) Final Vinyl product looks something like this after cut is complete
25) Release the Vinyl from mat:
- Remove mat from Cricut unit
- Flip mat onto a flat surface, Vinyl side down. Carpet floor works just fine. Secure Vinyl with one hand flat against surface, peel mat slowly from Vinyl with the other hand (instead of Vinyl from mat, this will result in less curl up Vinyl)
26) Using scissors or a paper cutter to cut SAW section from Vinyl roll, set aside for weeding step
27) For time savings, cut next sheet by repeating steps 17 - 26. If complete for the day, place protective sheet back onto sticky side of mat. This will extend life of the mat
28) Weeding the Vinyl sheet (do while next sheet is being cut or save for later. Your favorite beverage is recommend for this task ;-)
- Place the cut SAW Vinyl on a flat solid surface, such as a clip board, counter top or desk. I used a large clip board of sort, friendlier on the neck and the back
- Use an embossing tool or weeding tool to pick and remove each small tiny rectangles. The tiny rectangles are to be trashed, but the delicate outlines are kept, so be careful not to damage them
- When using an embossing tool, firmly press the balled point from the corner of a tiny rectangle & push up to release the adhesive back from the backing sheet. Use tweezers or fingers to remove tiny rectangles, and trash. Yes! There are a lot of them, all rectangles will need to be removed

29) Cut transfer tape from roll, it needs to be slightly larger than the Vinyl cut. The extra transfer tape will allow handling of the Vinyl onto 3D print later and easier removal of the transfer tape from Vinyl afterwards
30) Place transfer tape onto Vinyl, sticky side of transfer tape onto shiny side of Vinyl. Press down for good contact
31) Flip the whole thing over, transfer tape down, Vinyl backing sheet up. Pin transfer tape against flat surface with one hand, peel back Vinyl sheet to remove from transfer tape. Vinyl backing sheet will be completely removed, outer edges of the shiny Vinyl will be removed too. Once done, you will noticed, the sticky sides of the transfer tape and Vinyl are on the same side, one big sticker
32) For easier application of Vinyl to 3D print, cut transfer tape between the images to free each SAW outline from the group

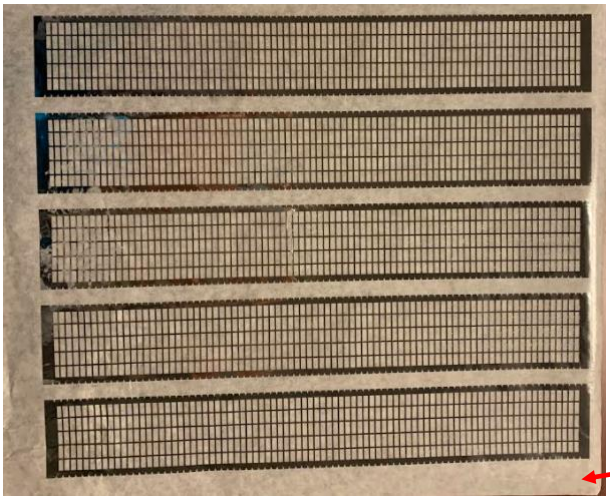
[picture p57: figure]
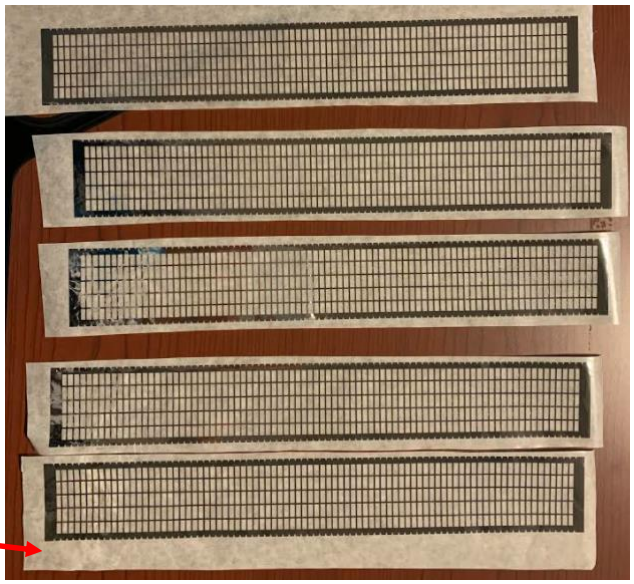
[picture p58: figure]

Transfer tape

After tiny
rectangles are
removed + onto
transfer paper

Cut

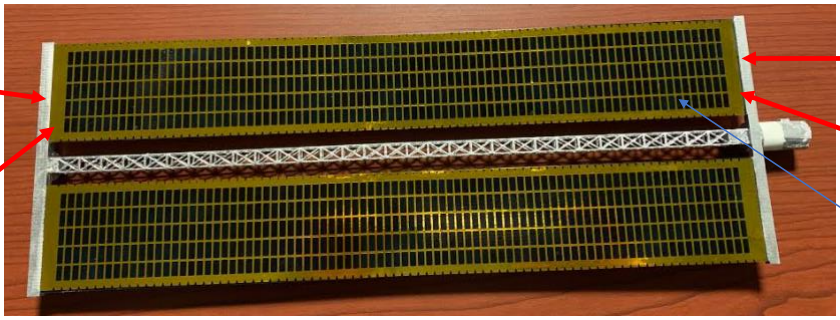
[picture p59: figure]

33) Transfer the Vinyl onto 3D print (blue side). Place a SAW Vinyl sticker sticky side up, horizontally on a flat surface
34) Holding 3D printed SAW with both hands horizontally, blue side down, align the blue edges of 3D print to be the edges of shiny Vinyl. Vinyl edges should just touching the silver areas, covering all the blue painted area of the 3D print
35) Once aligned, lower the 3D print onto Vinyl sticker. Flip 3D print over to check alignment. If adjustment is needed, peel the sticker off 3D print, and try again until alignment is properly done. (Backup vinyl panel is available if needed)
36) When ready, to secure adhesive to 3D print simply place the 3D print with Vinyl/transfer tape side down back onto a flat surface, use fingers, hand or under side of a fist to press down on 3D print to encourage better adhesion of Vinyl to 3D print
37) To remove transfer tape from Vinyl, flip the 3D print over with truss down (aka, transfer tape up)
38) Peel transfer tape off Vinyl, start from a corner, pull slowly at a 45 degree angle to peel transfer tape away from the Vinyl. Its useful to keep one hand on Vinyl against 3D print while the other hand pull transfer tape away (this is not a ban-aide, don’t rip it off fast, slow is the key)
39) Once complete, Vinyl will stay on the 3D print, transfer tape can be trashed. ISS panel would look like the above image

Silver edge of
3D print

Silver edge of
3D print

Gold edge of
Vinyl

Gold edge of
Vinyl

Blue painted area
of 3D print

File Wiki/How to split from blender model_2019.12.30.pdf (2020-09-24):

1. Open ISS Blender File. Can be downloaded here: https://nasa3d.arc.nasa.gov/detail/iss
2. While in Object Mode (located lower left)

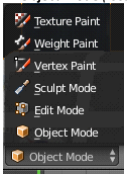
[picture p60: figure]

Start: 0.100 (default)
End: 100,000
3. Extend Clipping distance as follows, then hit ENTER button or click away from box

File -> User Preferences -> Input -> check "Emulate 3 button Mouse" -> Save User Settings Same can be done with "Emulate Numpad"

Click and hold middle mouse button to spin model. Click axis arrow then slid up/down/side to move model left, right, up or down. If middle mouse button is not available, you can Emulate 3 button Mouse by following these settings…

4.

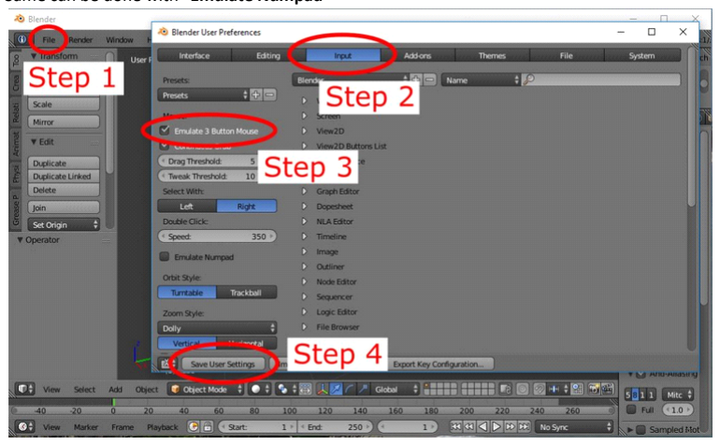
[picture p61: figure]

5. Locate piece of ISS to split

# How to split from blender model

Monday, December 30, 2019 12:14 PM

New Section 1 Page 1

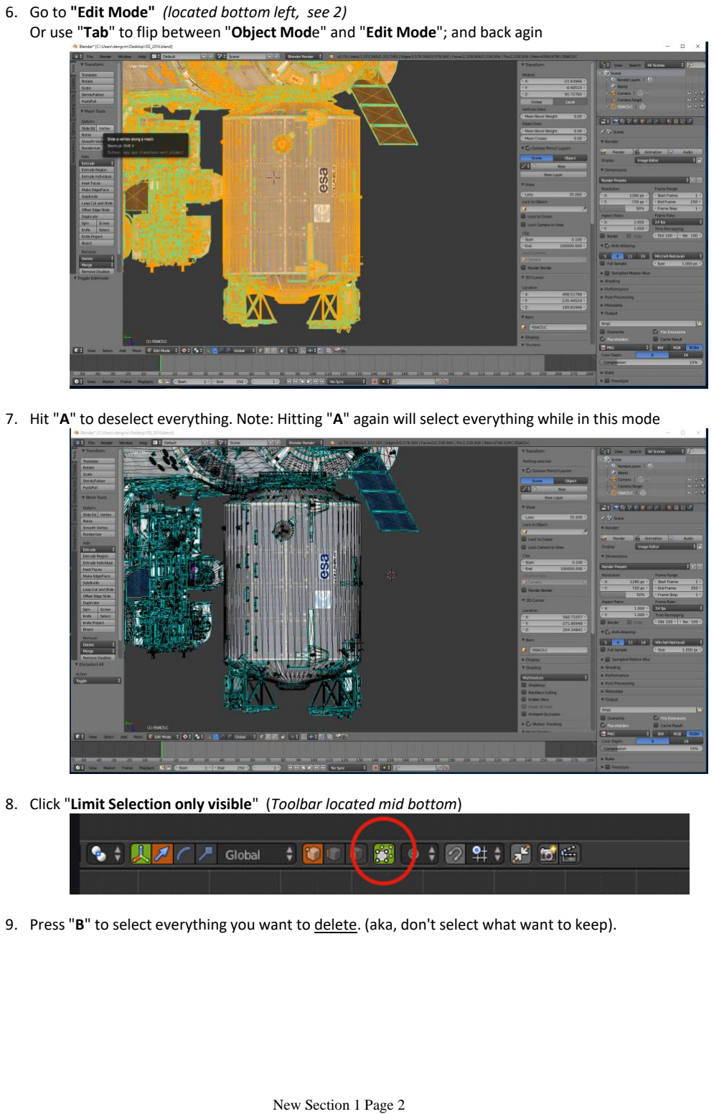
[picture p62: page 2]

6. Go to "Edit Mode" (located bottom left, see 2)
Or use "Tab" to flip between "Object Mode" and "Edit Mode"; and back agin
7. Hit "A" to deselect everything. Note: Hitting "A" again will select everything while in this mode
8. Click "Limit Selection only visible" (Toolbar located mid bottom)
9. Press "B" to select everything you want to delete. (aka, don't select what want to keep).

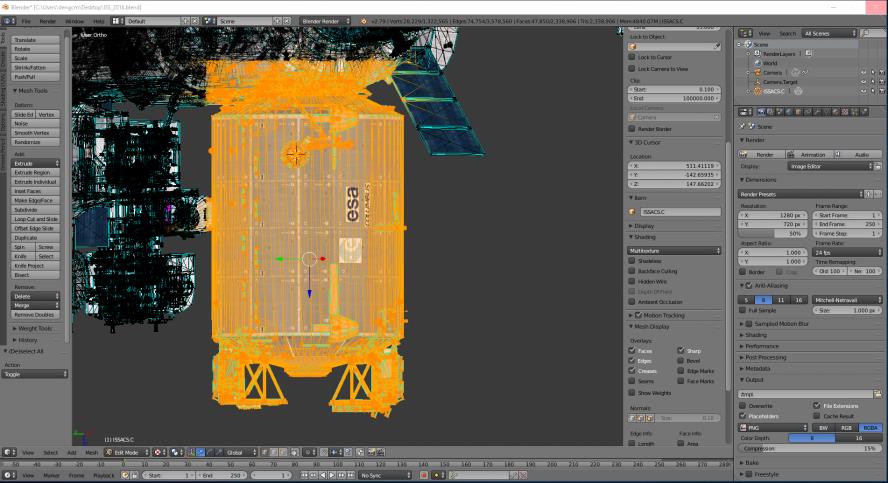
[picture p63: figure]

10. Press "X" to bring up the delete menu; then click "Vertices"

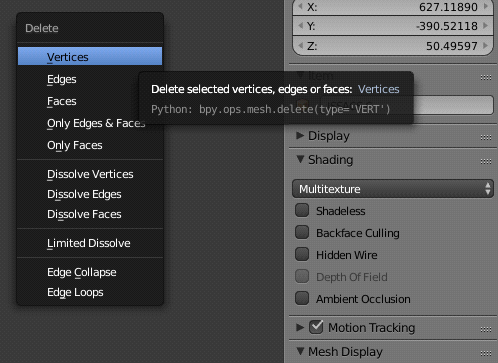
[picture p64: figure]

11. Repeat delete area until only the desire model piece wanted for printing remains

Note: If cursor has issues (aka, locked curser), pressing L while over something will select everything attached to whatever your cursor is over (but it’s a bit non precise, sometimes it will just jump to nearby faces). If it ever selects the wrong stuff, pressing A will unselect everything.
Note: Number pad 5 & then Number pad 1 will take you center to model if you get lost in the margin Note: Number pad "." will take you back to center of model

File -> Export STL
Select "Ascii" check box (left bottom ish)
Just above "Ascii", click Scale, then type in "0.0254" At top, title it, then click "Export STL" upper right
12. Saving file to STL format for printing:

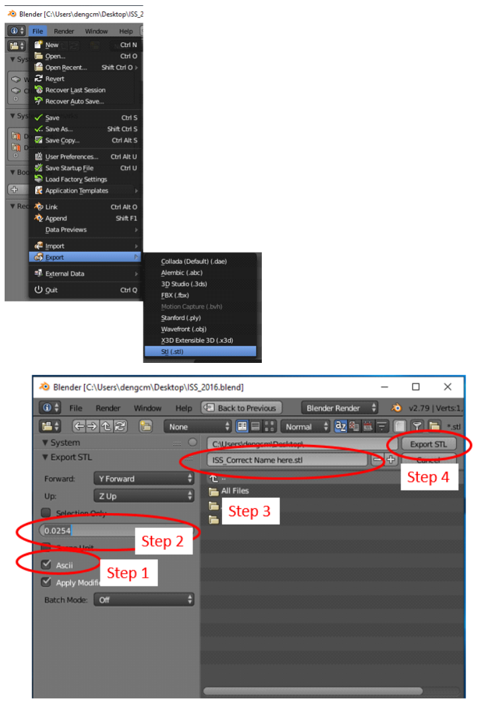
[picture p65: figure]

(Note: Scale display only display up to 2 decimal. So you will notice it will auto change to '0.03' after input of '0.0254'. Know that Blender will still apply the '0.0254' factor)

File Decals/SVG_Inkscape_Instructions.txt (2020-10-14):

File -> Import (select PNG image)

png bitmap image import options -> change image rendering mode to "smooth", click ok

top menu, click path -> "trace bitmap"

select "brightness cutoff" and set to 0.990, click ok (dialogue box doesnt go away, have to close it)

now delete the PNG imported image (the one which looks pixelated when you zoom in)

save as SVG? might set the stroke to off (under fill/stroke options)

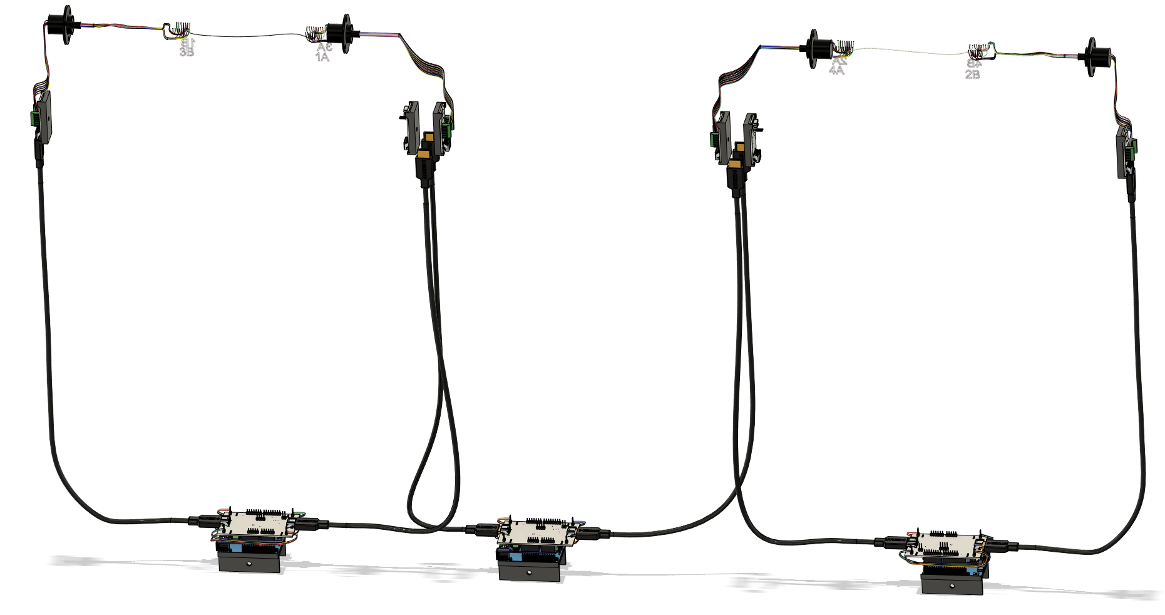
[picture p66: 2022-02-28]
Wiki/Images/Mimic_Wiring.png

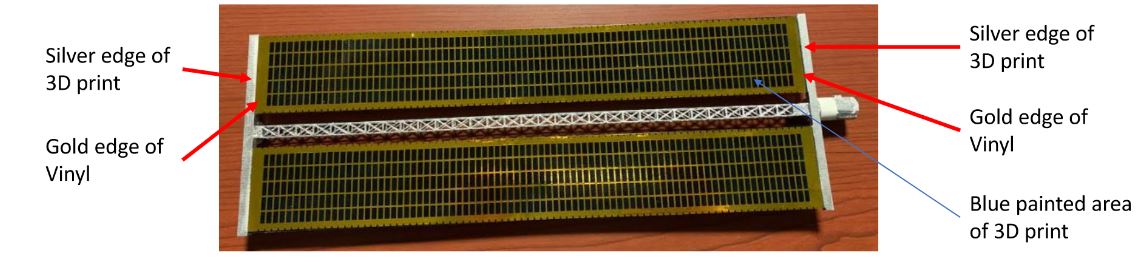
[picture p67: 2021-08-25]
Wiki/Images/VinylInstalledOnSaw.JPG

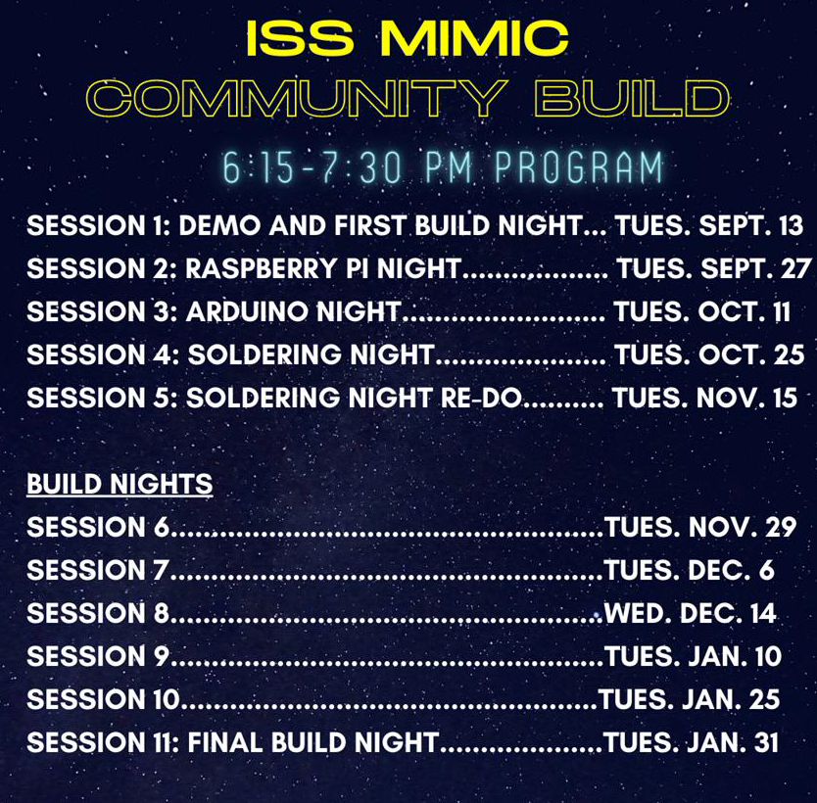
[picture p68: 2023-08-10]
Event_Pictures/FreemanLibraryCommunityBuildSchedule.png

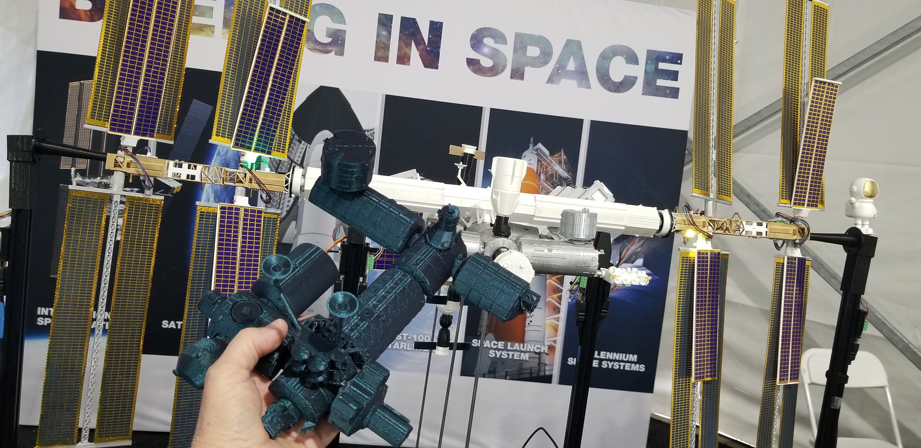
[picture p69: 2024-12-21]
Event_Pictures/2024Moon2MarsEduMimicTestPrint.jpg

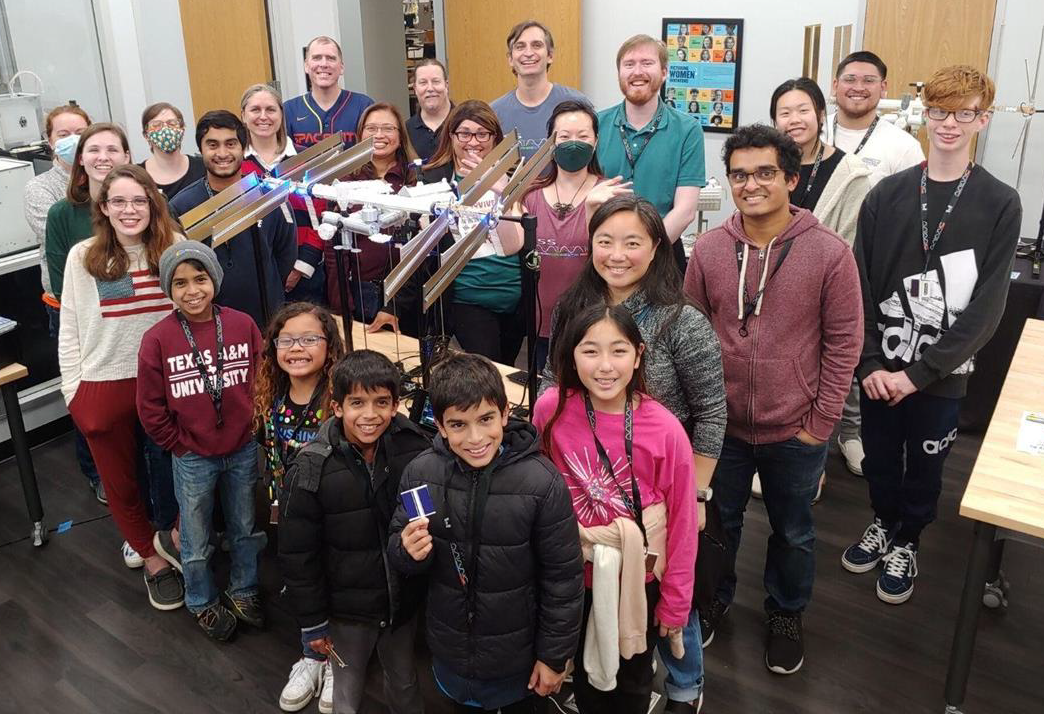
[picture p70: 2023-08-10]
Event_Pictures/FreemanLibraryCommunityBuild.png

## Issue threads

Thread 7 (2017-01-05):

Enough Interrupts on Arduino Mega?

juggler2000, 2017-01-05:
Each DC motor we are using has a magnetic encoder -- a magnet fixed to the motor shaft rotates past a hall-effect sensor, which generates a short voltage pulse.  To ensure every pulse is counted (and we keep track of where we are), interrupts are used which pause the running code on the Arduino and increment the count.

The Mega has 6 Hardware interrupts.  We'll need a total of 10 interrupts (8 for BGAs, 2 for SARJs).  Perhaps "software interrupts" can work, or we can have some shared hardware interrupts perhaps.

Specs on Mega: https://www.arduino.cc/en/Main/arduinoBoardMega

juggler2000, 2017-10-28:
Arduino Due seems to solve the limited interrupts problem, so we will abandon Arduino Mega.

Closed 2017-10-28.

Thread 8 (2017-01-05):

FYI: Motor info for connection to custom PCB

juggler2000, 2017-01-05:
This is the motor we are using right now (for BGA's and SARJ's): https://www.servocity.com/175-rpm-micro-gearmotor-w-encoder

And this is the mating connector: https://www.servocity.com/zh-series-jst-6-pin-connector-1-5mm-pitch

juggler2000, 2018-01-08:
Should we close this?  Seems like it needs to live somewhere, but it isn't an "issue".  I'm sure there's a place for such things, but it doesn't seem like it should be the wiki.

streadgold, 2018-01-08:
This seems like a good candidate to be a note "card" in one of the projects - I'll copy over

Closed 2018-01-08.

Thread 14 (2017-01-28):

Expected fight between LED's and interrupts -> Undetected joint angle error

juggler2000, 2017-01-28:
The LED libraries (both Adafruits and FastLED) temporarily disable interrupts when sending commands to the LED strips.  This is because the timing on the embedded control chips is very sensitive.

The potential issue is that we could miss some encoder-provoked interrupts while transmitting to the LEDs, meaning we could miss some encoder counts.  This would cause us to rotate the motors further than desired, and never know it.

It's not a big problem in the near-term, as the error would likely be small (although it would accumulate), particularly if we don't update the LED commands very often.

Potential solutions:
1) Command all motors to stop, and wait for them to do so, prior to updating the LEDs.  This is only feasible if we would rarely update the LEDs.
2) Estimate how much we have traveled while the interrupts were disabled based on the speed command, and update our counts accordingly.
3) Offload the actual commanding of LED's to a secondary arduino, dedicated to sending only LED commands.  This would require some kind of communication between the primary (Mega) and secondary.  Fortunately, the Mega has an unused hardware serial that could be used for this (or software serial or other protocol on other pins).  But this would add complexity to it all.
4) If we do get some kind of auto-calibration going, this could update joint angles as needed.  This means we'd be "wrong" most of the time, and only "right" immediately after calibration.  Our current calibration plan would only work when the SARJ is at one of two angles, and may require BGA's to be at particular angles as well.  So this calibration would be either infrequent or we'd have to think of an alternative approach.

juggler2000, 2017-01-28:
I guess an additional option is to command the LED's directly from the Pi.  But this would require parsing and extra work for the Pi, which would be nice to avoid.

streadgold, 2017-02-06:
Personally I like option 3, seems easiest and least risky to motor position error. Although there is a python wrapper for the neopixel library... so maybe commanding them directly from the Pi would be easier and we'd have to keep track of less data on the arduino side...

ISS-Mimic, 2017-02-13:
Commanding from Pi will not work - use of Neopixel library on Pi requires root access for devmem, root access (aside from being dangerous for an internet connected device) currently render GUI unusable for other reasons (freezes when fetching JSON info for crew screen).

Option #3 now seems likeliest/easiest to implement.

juggler2000, 2018-01-08:
Here's some Kung fu that may allow a single M0 ard to handle the motors and the pixels.  And, it does so by utilizing one of the SPI peripherals (magic).  And, it can do all of this on some bonus pins hiding in the middle of the board, ostensibly also providing a bag of chips.

https://learn.adafruit.com/dma-driven-neopixels/overview

ISS-Mimic, 2018-02-27:
Secondary arduino for LEDs seems to work just fine

Closed 2018-02-27.

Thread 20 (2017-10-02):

Arduino Due has pansy pull-up resistors, causes interrupt woes.  Solve with more resistors.

juggler2000, 2017-10-02:
Arduino Due has a plethora of pins available for interrupts -- any digital pin, actually.  It is recommended to avoid pin 13 since it's tied to an LED, but still, 53 pins.

Initial attempts to read encoder pulses as interrupts failed completely.  Typically, nothing at all happened.    Some web searches indicated that there is a known issue with the Due, where it's internal pull-up resistors are 100K-Ohm.  This leads to little sensitivity to an encoder pulse.  The reported solution is to use an (external) 2.2K-Ohm resistor tied to 3.3v as a pull-up resistor.  Tests show that this works super-fantastically, at least for two motors (with to interrupts each).

The best-case scenario yields using a total of 20 pins for interrupts.  This is two for each DC motor (8 BGA, 2 SARJ).

Will update issue once tested with more channels.

juggler2000, 2018-01-08:
The added resistors  worked for reading interrupts (solved above issue), but due to Due issue (see what I did there) covered in #32 (also rhymes), quitting on Due (yep) and moving to (kinda forced) M0 board.

Closed 2018-01-08.

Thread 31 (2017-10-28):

Adafruit Motor Driver v2.3 requires logic jumper change to work with Due (3.3v)

juggler2000, 2017-10-28:
The Arduino Due functions on 3.3v logic.  The Adafruit Motor Driver Shield v2.3 runs at 5v logic by default, but can be configured to use 3.3 volt by cutting a trace on the board and adding a solder jumper.

As of today (Oct 28, 2017) this link is quite dated, referring to a 1.5.6 version of Arduino.  It's assumed the logic/jumper information still applies: https://learn.adafruit.com/adafruit-motor-shield-v2-for-arduino?view=all

"For use with the Due or other 3.3v processors, you must configure the board for 3.3v logic levels. Find the set of 3 pads labeled "Logic". Cut the small trace between the center pad and 5v and add a jumper from 3.3v to the center"

juggler2000, 2018-01-08:
This worked for reading interrupts (solved above issue), but due to Due issue (see what I did there) covered in #32 (also rhymes), quitting on Due (yep) and moving to (kinda forced) M0 board.

Closed 2018-01-08.

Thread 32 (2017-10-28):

Arduino loop time toggles between 7 and 615ms

juggler2000, 2017-10-28:
For some reason, the Arduino Loop time (start to finish within loop function) is either 7ms (yea!) or 615 ms (boo) with no known cause.  It's never anything in between.  It doesn't seem to matter if the motor shield is powered externally or not.

I couldn't find any floating ground or other impropriety.  There doesn't seem to be anything in the loop that would cause the system to wait for anything.  Serial comm with PC is at high rate (115k).

Hitting the reset button seems to eventually put it into the slower state.  Sometimes, unplugging and re-plugging the USB from the PC gets you back to the fast mode.

My only thought would be something with the interrupts, or perhaps demon possession.

Here's an example of it going from swell to hell.  All I did was press the reset button on the motor shield.  The serial output says "Motor test" a that point.  The last value on each line is the loop duration, in ms.  It's also obvious from the rate of serial prints to the screen that it's taking much longer.

190.00,32.40,250,6714.67|,190.00,33.40,250,3540.57, deltaT:7
190.00,33.20,250,6690.51|,190.00,34.00,250,3536.37, deltaT:7
190.00,34.00,250,6666.31|,190.00,34.80,250,3528.13, deltaT:7
190.00,34.80,250,6642.07|,190.00,35.60,250,3519.85, deltaT:7
190.00,35.40,250,6625.80|,190.00,36.40,250,3511.53, deltaT:7
190.00,36.20,250,6601.49|,190.00,37.20,250,3503.17, ⸮Motor test!
190.00,143.20,250,1872.00|,190.00,139.20,250,1016.00, deltaT:617
190.00,191.40,55,-56.00|,190.00,186.20,87,87.78, deltaT:616
190.00,239.40,250,-2128.89|,190.00,233.20,250,-864.00, deltaT:616
190.00,288.00,250,-4376.20|,190.00,279.80,250,-2073.93, deltaT:616
190.00,336.60,250,-6773.93|,190.00,326.40,250,-3428.09, deltaT:616
190.00,374.00,250,-8839.41|,190.00,360.40,250,-4635.48, deltaT:615
190.00,380.20,250,-9675.13|,190.00,365.00,250,-5268.23, deltaT:616

juggler2000, 2018-01-01:
I asked for help on Adafruit's forum, and Adafuit staff essentially said that the Due is problematic and suggested avoiding it.  They pointed me to an M0-based board to get the number of interrupts we need without the headaches of the Due, so I ordered one of their "M0 Metro" boards and should have it later this week.

https://forums.adafruit.com/viewtopic.php?f=31&t=128661

SupaTreadz, 2018-01-02:
That would also resolve issue #32a "No one knows how to pronounce Due"

juggler2000, 2018-01-08:
Using Arduino Metro M0 with aforementioned motor shield, no longer having any of the timing problems.  Working perfectly with 3 DC motors and 1 servo.  Will try with more motors soon, but this ~~solves~~ abandons the timing problem by moving to M0 board.

Issue resolved by murdering Due and moving to M0-based board.

Closed 2018-01-08.

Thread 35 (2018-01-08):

Passing data (joint angles, etc) from RasPi to Ard

juggler2000, 2018-01-08:
I was thinking one way to pass data for joint angles, etc, is via the .json standard, which uses named pairs: name, then value.  We could perhaps use an existing json library, like this: https://arduinojson.org/

SupaTreadz, 2018-01-08:
Can do! Python makes JSON wrapping super easy

juggler2000, 2018-01-15:
Leaning towards this Ard Json library, as it appears most widely used.  Currently have not clue how to use it.
https://arduinojson.org/

juggler2000, 2018-02-05:
Does the Pi send data over serial by default, or do I need to hit "transmit".  GUI seems to lock up every time I hit transmit (the GUI is unresponsive, requiring hard reboot).

streadgold, 2018-02-05:
If the Pi is locking up that means the Arduino isn't connected or it isn't detecting the Arduino. When booting the Pi, along with the kivy loading stuff it should list the connected serial port if there is one. Also in the error log file (in logs folder) it says if a successful connection occurred, if there are three serial connection errors listed it didn't connect to anything.

This is connecting one of the Pi USB ports to the Arduino USB port right? Try another USB port on the Pi?

streadgold, 2018-02-05:
Also I've only managed to get it working with USB to USB, so debugging might be tricky. Still working on USB to TX/RX pins

juggler2000, 2018-02-05:
I forgot it would lock up w/o connection.  Iwas being cruel, and just had
serial pins going from Pi usb to O-scope.  Now trying the TX/RX pins (via
logic level shifting).  We'll see.

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

streadgold, 2018-02-07:
Just FYI - I just tested my Mega connected to the Pi over USB and outputting serial to the computer over the TX1/RX1 pins. The code is in the Arduino folder. Not sure what needs to change for that to work on the your board but the concept works fine.

ISS-Mimic, 2018-02-27:
Closing, I believe our tests confirm we have this problem down

Closed 2018-02-27.

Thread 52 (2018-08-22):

Innovation Week Goals

GodspeedDiscvry, 2018-08-22:
**Double the Size**

- [x] Get metal for test stand to support full station
This is done for now - but still acquiring better metal and longer metal for more stability.  We can even live with the diagonal sick going up into N2N since we don't have an HTV print yet.

- [x] Integrate pressurized section in full size test bed to illustrate size and magnify interest.
For the most part this is done.  We are adding more pressurized elements.  I will need to eventually move the module stack on its base (and redrill holes for RS) to accommodate the longer Lab module - but think the diaganol support will work for I-week.

- [x] Determine post material (metal/acrylic, etc.) to support pressurized elements and route wires, possibly with LEDs inside and/or flags/etc. outside.

- [x] Determine where to cut cross pieces of 80/20 (currently 30+ inch, prob drop to 28ish)
I propose we do not do this at this time.  I may need one of the longer feet  to use for module stack support

- [x] Print or procure end caps for extruded aluminum (because it's sharp).  https://www.thingiverse.com/thing:1876628

- [x] Print support caps for risers and spindle

**3D prints still needed for module stack in order of priority (to support above "Double the Size" goal)**

- [ ]new caps for Lab with magnet insets
- [ ] S0/Lab connector piece
- [ ] PMM
- [ ] Cupola (if we had CAD model done)
- [ ] JEM
- [ ] JLP

**High Def Models**

- [ ] See truss structure when not MLI

- [x] Resolve Blender model issues

- [ ] Handrails & details?

**Mechtronics**

- [ ] Functional TRRJ

- [ ] ARD cmd = 10 DC motors + 2 servos + LEDs

 **Pressurized**

- [ ] Focus some LEDs into a functionality

**GUIS**

- [x] Un-eWeek backgrounds

- [ ] ideas for subsystem page content

- [ ] Al pages present with some level of content and standard GUI MIMIC template

**Stretch**

- [ ] AR/Unity - where is the sun?
- [ ] Print all in SLA

ISS-Mimic, 2019-01-23:
Actually accomplished most of this and I-week is over, closing. We can maintain new issues with the new truss backbone on Issue #77

Closed 2019-01-23.

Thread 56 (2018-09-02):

Twitchy Connections

ISS-Mimic, 2018-09-02:
Our IEA battery LEDs could use some permanently soldered connections so they don't act as twitchy. If our LEDs are twitchy perhaps that also might affect the encoders?

ISS-Mimic, 2018-09-28:
Seems to be solved

Closed 2018-09-28.

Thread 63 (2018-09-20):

Extrusion Components

Digisembler, 2018-09-20:
- [x] Model 8020 nut for attaching to extrusions.
1/8 inch hole for rods
need design, stls and makerbot pla sliced files
- [x] Model 8020 cone for attaching to extrusions.
1/8 inch hole for rods
need design, stls and makerbot pla sliced files

Digisembler, 2018-09-26:
- [ ] Print SAW end caps (2)

- [ ] Print SAW canisters (2)

- [ ] Print Node 2 body

- [ ] Print Node 2 cap

- [ ] Print JEM PM

- [ ] Print JEM EF

- [ ] Print JEM ES

- [ ] Print replacement COF body

Digisembler, 2018-09-28:
- [ ] Explore ELC models from Blender model.

- [ ] Modify ELC1 models to have small magnet at CAS interface, FRAM/direct mount sites/ExPCA/Grapples
- [ ] Modify ELC2 models to have small magnet at CAS interface, FRAM/direct mount sites/ExPCA/Grapples
- [ ] Modify ELC3 models to have small magnet at CAS interface, FRAM/direct mount sites/ExPCA/Grapples
- [ ] Modify ELC4 models to have small magnet at CAS interface, FRAM/direct mount sites/ExPCA/Grapples
- [ ] Modify AMS model to have small magnet at CAS interface, Grapples

juggler2000, 2018-09-29:
This list is fantastic.  Which are print-ready?

Digisembler, 2018-09-30:
working... btw, i completed a Lab mod (and printed it) that has two beautiful endcones and a cylinder (PLA is my BFF!)
Also, need some help (thoughts/technical?) on how to setup/upload stls here...

streadgold, 2018-09-30:
If you go to the Code section, I just added a "Printing" folder, if you click on that then "Upload Files" at the top you can upload them there. Not sure what our file size limit is for our whole repository but STLs usually aren't that big right?

Digisembler, 2018-09-30:
Great thx.  Any way to edit the text with the commit after committing? i forgot to add the ELM PS print notes... (i.e. I'd add" Print the non-cbm end down, no supports. Again, PLA recommended.  Also setup for a magnet for the PIU interface on the top, same size as PM").

streadgold, 2018-10-01:
Not sure if you can edit a commit message

streadgold, 2018-10-01:
Oh so you can add comments to each commit, might be easier than editing it.

Also Craig, your commit messages put mine to shame haha. Mine are all "added stuff, changed things"

Digisembler, 2019-01-03:
Ok, 2019!  I have the S6 (P6) array mount printed.
I fixed the S1 model (rotated the motor mount hole) and am printing now (~ 4 hrs)
We should clean up the above list of things to print, i think it's outdated and start a new one soon.

ISS-Mimic, 2019-01-23:
Yep, concur. Closing this issue, add any new components and tasks to Issue #77

Closed 2019-01-23.

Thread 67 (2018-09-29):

P3 CAD model cavity not quite large enough to insert SARJ motor

juggler2000, 2018-09-29:
Cavity is perfect to house motor assembly, but not quite "long" enough to insert it due to shaft protrusion.  Could either elongate rectangular slot or make motor shaft hole a bit "deeper" towards centerline of truss.  Plan to file the one we have.

Digisembler, 2018-09-30:
ok. i agree for now to mod it - this is the same file as the blue one that works... is it possible that the motors have a bit of individual tolerance buildup? (yes, it is possible...)  can amend as needed.

Digisembler, 2018-10-04:
Dremeled slight angle to the axle hole, that did the trick.  Highly approve the instantaneous SLA support removal method (gravity assisted force applied to the object...) - but i don't suggest trying this at home. :P

Closed 2018-10-04.

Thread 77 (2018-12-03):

Transition model to new black aluminum structure

streadgold, 2018-12-03:
Highest priority is getting the port outboard truss up and running again.

- [x] Requires new mounting interface for S3/P3

- [x] Need threaded rod and nuts to tighten truss

- [x] Wiring #80 needs to be accomplished

- [x] Print new truss endcaps

feel free to edit and add more...

@Digisembler @GodspeedDiscvry @juggler2000

Digisembler, 2019-01-24:
Modified the truss endcaps to match the new heights.  Printed those in black PLA.
Reprinting the S1/P1 Mounts in black PLA (fixes/completes S3/P3 new mounting above).
#3 x 36" threadrod and nuts ordered to tighten inboard truss.  (really wondering why we didn't just use a flat bar and set screws in each module... would have been easier/tighter... just thought of it, so, that's probably why, but doesn't really keep the stack axially tightened.)

ISS-Mimic, 2019-01-24:
Bueno! If it was difficult to find the rod/nuts it might be worthwhile to link the part numbers / links to the products somewhere here for future reference

Digisembler, 2019-01-24:
Nuts:
https://www.grainger.com/product/2GA49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

Threadrod:
https://www.grainger.com/product/21YN98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

We'll see if these work when they get in.

Digisembler, 2019-02-06:
Threadrods delivered, cut, installed with nuts.  New zip-tie outboard support blocks designed/printed (need small zip ties for today... no wider than 1/8", probably 3-5" long, minimum of 4 needed)

ISS-Mimic, 2019-02-07:
Completed - or at least back to where we were on the old frame. Will bring zip ties tomorrow

Closed 2019-02-07.

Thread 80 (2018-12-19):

Truss Cable Choice

streadgold, 2018-12-19:
Related to Issue #74

We talked about using cat-7 cables for the runs down from the truss back to the arduino but maybe we should actually use USB-C?

Pros:
USB-C are 12-pin cables, perfect for our 12-pin slip rings. So 4 cables total coming from truss, instead of 8.
USB-C are slimmer and look more high-tech?

Cons:
Breakout board would have slip ring wires soldered directly on, wouldn't look as clean.
Breakout board is a little wide and wouldn't hide as well as ethernet doubler

Thoughts?
@Digisembler @GodspeedDiscvry @juggler2000

streadgold, 2019-01-07:
USB-C won't work :(

They require magic electrical nonsense to work. Back to ethernet

ISS-Mimic, 2019-02-06:
Ethernet it is.

Closed 2019-02-06.

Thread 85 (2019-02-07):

Motor problems

ISS-Mimic, 2019-02-07:
After re-wiring, motors don't work properly. LEDs seem to work properly though, so the 3.3v power, gnd, and neopixel data lines probably all are fine.

Need to determine if all pins are connected properly before the custom shield PCB is designed.

ISS-Mimic, 2019-02-07:
Solved! Had to switch a few wires. Back up to our peak functionality

Closed 2019-02-07.

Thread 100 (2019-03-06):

Save ISS Live!!!!

streadgold, 2019-03-06:
~~Mark Guerra at Tietronix (front end host of ISSlive.com) stated that NASA dismantled the telemetry server. Evidence to the contrary exists and without NASA confirmation, we can't be sure of anything.~~

isslive.com is no longer receiving telemetry updates.

We have confirmation that the ISSlive project has been defunded and at this moment is completely dead. The lightstreamer server is still up but will not receive anymore data from the ISS. We are attempting to save it using everything in our power.

streadgold, 2019-04-09:
It has now been confirmed by NASA that ISS live was defunded and there are no efforts to revive it :(

ISS-Mimic, 2019-04-26:
:warning: Not to get overly dramatic but the ENTIRE FATE OF ISSLIVE AND MIMIC COULD BE DECIDED THIS COMING TUESDAY :warning: :warning: :warning: :satellite: :satellite: :satellite: :earth_americas: :rocket: :rocket: :stars: :star2:

ISS-Mimic, 2019-08-30:
!!!!!!!!!!!!!!!!!!!!!!!!!!!!!!!!!!!!!!!!!!!!!!!!!!!!!!!!!!!!!!!!!!!!!!!!WE DID IT!!!!!!!!!!!!!!!!!!!!!!!!!!!!!!!!!!!!!!!!!!!!!!!!!!!!!!!!!!!!!!!!!!!!!!!!! :tada: :confetti_ball: :rocket: :confetti_ball: :tada: Thanks mostly to Bryan's extraordinary ability to pester the right people, ISSlive will be returning to an interweb near you this fall!

Not closing the issue until it is back up and running but this is really happening and it is mostly because of this project. Epic epic epic epic epic.

:tada: :confetti_ball: :rocket: :confetti_ball: :tada: :tada: :confetti_ball: :rocket: :confetti_ball: :tada:
:tada: :confetti_ball: :rocket: :confetti_ball: :tada: :tada: :confetti_ball: :rocket: :confetti_ball: :tada:
:tada: :confetti_ball: :rocket: :confetti_ball: :tada: :tada: :confetti_ball: :rocket: :confetti_ball: :tada:
:tada: :confetti_ball: :rocket: :confetti_ball: :tada: :tada: :confetti_ball: :rocket: :confetti_ball: :tada:

streadgold, 2019-09-16:
ISSlive! is officially back up and running

http://demos.lightstreamer.com/ISSLive/
isslive.com

ISS-Mimic, 2019-09-16:
CLOSING ISSUE!!!!!!!!!!!

dziban303, 2021-01-12:
That didn't last very long. It's been down since June

ISS-Mimic, 2021-01-12:
> That didn't last very long. It's been down since June 2020.

Hi dziban303, that's not quite accurate. We record all the telemetry coming off ISSlive and monitor it's status constantly.

ISSlive has been offline since December 15th due to the Solarwinds cybersecurity incident, however the system is scheduled to be restored sometime this week. This current outage is the longest the system has been offline since it was restored back in September 2019.

dziban303, 2021-01-12:
Thanks for the reply! I last checked it when the most recent hunt for an air leak was going on, so I guess that was September, and it was working then; when looking for some news about why it was down now, I saw tweets from people saying it was down going back to June. After hearing about the plan to install new solar panels next year, I checked this evening to see how much power they were producing now.

Anyway I'm glad it'll be back up soon. Having the ability to see what's going on with ISS makes it much more "real."

Cheers

ISS-Mimic, 2021-01-12:
No problem! There are occasionally a few days or a week long outages due to server issues but if it lasts longer than a week we'll reach out and make sure the team is aware that the public data feed isn't working.

I'll need to graph the US lab cabin pressures from the air leak sometime, should have that data recorded.

We're excited about the new solar arrays too, from the public telemetry (if I recall correctly) the solar array current/voltage values actually reflect the DCSU output, so it's more like the actual downstream power usage than power production capability. But that value seems to typically be around 40-60kW. Will be interesting to see how things change with the new arrays

ISS-Mimic, 2021-01-20:
Heard back from ISSlive that they are still having problems but definitely still working on restoring the public data stream

ISS-Mimic, 2021-01-22:
The telemetry has returned!

dziban303, 2021-01-22:
So it is! Thanks for the update. https://isslive.com is still not working. I'm actually glad it broke, because otherwise I wouldn't have found this project, which I think is super cool. Cheers!

ISS-Mimic, 2021-01-22:
Not sure what the problem with isslive.com is, but that site is no longer run by NASA so not sure how much effort is being made to maintain it.

Glad you found us though! We have our two pages that show all the live telemetry https://iss-mimic.github.io/Mimic/ and https://iss-mimic.github.io/Mimic/dashboard.html (and fun fact about those pages, we might be the only place on the web to view ALL OF THE TELEMETRY! that I know of at least, because the Canadian Space Agency got a bunch of robotics data added after the launch of isslive and to my knowledge no one else is displaying that data).

While our two web pages aren't as graphically interesting and isslive.com, our Raspberry Pi software, while still definitely in development, has the goal to display all of the telemetry in a more interesting graphical format than isslive.com.

The Raspi GUI currently shows a few things in its current state like the solar array data with animations showing whether or not the arrays are sunlit, and if the batteries are charging/discharing. Also has a needle gauge that shows the pressure in the airlock which is fun to watch during spacewalk prep, and we also show which satellite the SGANT antenna is pointing to and which antennas are broadcasting. We are always looking for new ideas on interesting ways to visualize the telemetry without just showing the raw numbers so let us know if you have any ideas. I am also putting together a wishlist of telemetry that is not currently available in the public stream but that I plan to request they add to the public telemetry stream.

The full list of public telemetry with detailed info can be seen here by the way: https://github.com/ISS-Mimic/Mimic/blob/master/ISS_Public_Telemetry.xlsx

Closed 2019-09-16.

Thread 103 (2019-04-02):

Redesign truss for rewiring effort

streadgold, 2019-04-02:
Need to allow for wires inside truss, passing between p6/s6 motors and space inside IEA for wires to attach to boards

ISS-Mimic, 2019-05-30:
Mostly done, didn't read, submitted new issue. Oh well.

Closed 2019-05-30.

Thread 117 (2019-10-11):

Switch to Raspberry Pi 4

ISS-Mimic, 2019-10-11:
Currently the installation steps do not work on the Pi 4. Don't know why. Seems to work fine at first but then after a reboot the xserver completely fails and Pi is terminal only.

streadgold, 2019-10-13:
Solved. The "sudo apt-get install git-all" command does.... something. No idea what. but it completely nukes the graphics ability of the pi. Also - it's not needed. Git comes installed by default. Removed that instruction from the setup instructions

Closed 2019-10-13.

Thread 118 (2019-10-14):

Potential SARJ drift

ISS-Mimic, 2019-10-14:
When running in live mode for several hours it looks like the SARJs begin to drift by quite a bit. Both stay in sync with each other but they both appeared to be roughly 45 degrees off the actual angle after running for approximately 4 hours.

SWGlassPit, 2019-10-14:
Does the drift happen if the joints are commanded through multiple full
rotations via the calibration screen? Might rule out something simple like
having the wrong number of encoder pulses per rotation

On Mon, Oct 14, 2019, 17:09 ISS Mimic Project <notifications@github.com>
wrote:

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

ISS-Mimic, 2019-10-14:
Yes drift still occurs through manual control, a single full rotation appears to be about 30 degrees off

ISS-Mimic, 2019-10-24:
@juggler2000 do we think this is solved now?

juggler2000, 2019-10-24:
Yes, solved.

On Thu, Oct 24, 2019, 1:21 PM ISS Mimic Project <notifications@github.com>
wrote:

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

Closed 2019-10-24.

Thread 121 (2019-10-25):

Build Instruction - Install motors in components

GodspeedDiscvry, 2019-10-25:
Add to "Install motors in components" section on Build Instruction Wiki

    mount motor in truss print (screw and don't jam magnet)
    include wiring notes/sequences (especially for use inclusion of PCBs)

***or provide me word document and I can organize/get it into the wiki***

juggler2000, 2024-01-10:
This will be part of the EDU activities run by the teachers, so closing here.

Closed 2024-01-10.

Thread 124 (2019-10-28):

Major power draw problem

ISS-Mimic, 2019-10-28:
Some kind of issue where we seem to be drawing too much current from the Raspberry Pi USB ports, likely due to the added neopixels and servo motors being powered directly off the USB port.

Seems like the solution is to separately power the servos and/or the neopixels so they don't all draw from the Raspi USB ports which should not be used to provide more than 1.2A total from all 4 ports.

juggler2000, 2019-10-30:
Hmmm... disconnecting one of the servos solves the problem.  Sometimes, so does disconnecting half of the LEDs.  Initial test of powering STBD servo separately (from hacked USB cable plugged into same battery power brick that's powering the Pi). Yielded good results, but only from nominal motor commanding, so nothing drawing much current.

streadgold, 2020-11-14:
Solved with the powered USB hub

Closed 2020-11-14.

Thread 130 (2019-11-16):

Pi needs serial monitors

juggler2000, 2019-11-16:
Need to have serial monitors for each connected device, since the motor-driving Ards send info back.

This would be Uber helpful when debugging motor oddness.

streadgold, 2019-11-18:
So reading from the serial ports shouldn't be hard. Where would we display the data from the arduinos? Presumably most of the debugging would be done from the manual control screen, which is pretty busy. We could have it in the status bar at the bottom but that is only good for one ish line at a time. Or have a subscreen that has a lot more real estate but you'd have to switch back and forth to issue commands. Thoughts?

streadgold, 2020-11-13:
@juggler2000 given all the serial difficulties I'm not sure this will ever happen - is this issue also solved by just using the LCD screens on the HDMI shields?

juggler2000, 2020-11-13:
Yep, LCD screens should be just as good.  Maybe better, since we could always have data scrolling.  The downside is that we won't be able to see all of the data.

streadgold, 2020-11-14:
Closing for now since this likely won't happen. If serial usage works out well with the new code we may revisit this later

Closed 2020-11-14.

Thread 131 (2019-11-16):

Random Port SARJ misbehavior

juggler2000, 2019-11-16:
Works fine, then sometimes runs away perpetually spinning.

Worked fine for 2 hrs, then seemingly spontaneously manifested the problem.  Prior grounding issue did not appear to be cause.

Having made no changes but starting again, it works fine. Note that live data feed is currently down but was working during bug manifestation. Seems likely unrelated.

Doesn't seem like it should be a power issue since Hall encoder sensors are powered from pi which was still up, battery pack over 50 perc.

ISS-Mimic, 2020-08-08:
Closing old issues that are likely due to connection problems - which should be solved by our hdmi-ification

Closed 2020-08-08.

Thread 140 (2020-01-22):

Serial issue on new SGANT test

streadgold, 2020-01-22:
Testing the stepper motors on the new SGANT extra build and when we plug in the arduino the pi completely locks up but after removing the print statements from the arduino side the pi doesn't lock up but it becomes super laggy. Removing the USB cable instantly solves the problem.

Feel like we've had this problem before

streadgold, 2020-01-31:
Switched to Servos and finished the new code. And the problem still persists.

ISS-Mimic, 2020-01-31:
SOLVED! Problem was the GUI was using "timeout=0" in the serial write command, but timeout is for serial read timeout, we must use "write_timeout=0" to make a non-blocking serial write command

Closed 2020-01-31.

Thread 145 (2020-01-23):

Mimic Extra - SGANT motor issues

ISS-Mimic, 2020-01-23:
On the 20% SGANT build - the stepper motors are having trouble rotating the assembly back to zero from extreme angles.

Will attempt with 12V stepper motors (same form factor). If that doesn't work we will need to convert the entire build to more powerful stepper motors.

ISS-Mimic, 2020-01-28:
Switching to high torque servos

Closed 2020-01-28.

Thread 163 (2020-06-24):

IEA connector idea for interfacing with slip ring leads

juggler2000, 2020-06-24:
Would like something that allows leads from slip ring to be able to be inserted/removed from truss w/o cutting.  Most connectors are too big.

Screw terminals?  Smaller than 0.1” spacing?
Ribbon cable?  Might not be sufficient to carry current.  Could potentially use multiple traces for single current path (i.e. 4 traces for 2 motor power lines).

ISS-Mimic, 2020-08-08:
Screw terminals should work

Closed 2020-08-08.

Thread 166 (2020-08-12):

Redesign HDMI PCBs to use DIP connector 1.6mm spacing

ISS-Mimic, 2020-08-12:
Update PCB designs to use easier to solder connectors

Digisembler, 2021-07-21:
These connectors are very difficult to find, but we have redesigned PCBs to use Screw Terminals instead which solves the hard to solder problem - Sam

Closed 2021-07-21.

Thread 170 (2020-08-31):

Printed Microcontroller Holder

ISS-Mimic, 2020-08-31:
Would be nice to have a method of securing the Metro board to the frame.

CAD model of the metro should be here:

https://github.com/adafruit/Adafruit_CAD_Parts/tree/master/2488%20Adafruit%20Metro%20328

cactus314, 2021-06-29:
Preference for a holder that can be fastened to the 2040 extrusion or just held in place with a light press-fit?
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

Digisembler, 2021-07-21:
Patrick's solution seems to work well, might watch out for future issue of the screw hole pillars breaking off

cactus314, 2021-07-25:
Uploaded the Metro 2040 Mount to the structural components directory of the 3D Printing folder.  I'll let @streadgold rename/move it if he wants.  It fits the middle Metro pushed all the way against the t-brackets without too much side torque from the HDMI connection.  I'll design a separate mount for the Metro Mini I intend to use for the NeoPixels.
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

cactus314, 2021-07-28:
Uploaded STLs for mounts for the Metro Mini (i.e, Arduino Nano) considered for use to control Neopixels,  as well as a mount for the Sabrent 4-Port USB Hub.  These additions might close out this issue.  I'll let someone else (@streadgold / @ISS-Mimic ) decide.
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

streadgold, 2021-07-28:
Nice! Looks good to me

Closed 2021-07-28.

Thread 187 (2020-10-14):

Replace LED-driving Ard Mega with Nano or similar

juggler2000, 2020-10-14:
Just to have smaller footprint on the frame.  Of course, we eventually want a single Ard running everything....

cactus314, 2021-08-17:
So far:
- Metro Mini is recognized by the RPi, but doesn't register serial commands from it.  (I've reached out for advice on the subject from a knowledgeable friend.)
- Trinket M0 registers the serial commands, but has only a single ground pin - need at least two
- Will try a Nano clone next.  Don't expect any problems, but Nanos have a Mini USB connector rather than the preferred Micro USB
- Have ordered a Sparkfun Pro Mini to try as well

cactus314, 2021-08-22:
- Still have no success with the Metro Mini, but will continue to try.  It would be the best solution if only it would work.
- The Nano clone seemed to work, at least as well as I could tell from the STEM model which has some 'finicky' LEDs, making it hard to validate the Nano as a robust solution.  There's still the issue of having to use a USB-Micro cable for the Nano, plus there are circuit elements mounted to the bottom of the board, making it a little more challenging to design a proper holder.
- The Sparkfun Pro Mini is like the Metro Mini - it is "seen" by the RPi, but the Pro Mini doesn't appear to register any serial commands sent to it by the RPi.  Also, from Sparkfun's own webpage: "_Getting the Pro Micro or Fio v3 set up on your computer and in your Arduino environment can be difficult._"  It really wasn't any worse than setting up the Arduino IDE for the Adafruit Metro 0's, but it's also easy to brick the Sparkfun Pro Micros - I almost did.  Not sure I like it as a solution.

cactus314, 2021-08-24:
I do have a Nano clone working to control the Neopixels, but it's a bit persnickety.  Sometimes you have to reset it for the serial data to register, then it shows up as a 5th Arduino connected to the RPi on the Mimic GUI.  Not sure what's causing that.  It does take up a smaller footprint (see comparison images below), but I can only find them in 3-packs without the headers soldered in place, so there's not much cost savings over just using a 4th Metro 0, except then you get two extra Nanos to play with.  The Metro 0 never seems to give any problems and simplifies uploading the firmware (only one board to have to set configurations for), and would mean all the USB cables would be the same (the Nano would require a USB-Mini).  I'm not sure the benefits are all that great.
I'll let y'all vote on whether to go forward with using a Nano or stick with a 4th Metro 0 and consider closing this ticket.  I'm fine with either solution.

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

ISS-Mimic, 2021-08-24:
Alright, I'm fine with just using a 4th metro then, seems like the best option.

-Sam

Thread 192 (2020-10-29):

Improve Serial Port Detection

ISS-Mimic, 2020-10-29:
Currently, the serial ports are hard coded to ACM0 ACM1 ACM2 and ACM3. These are the most comment ports for our devices, but other devices or more/less devices would not work.

Added code to the "serial_ports" which checks all possible ports - this worked great but when actually using it when the connected devices there was considerable lag. We call it every 1 second ish and try to write to all those ports so... yeah.

Would be nice to detect whenever a device is plugged in or removed and update arduino_count accordingly (also need to handle other serial ports)

dallasbrittany, 2020-11-08:
Are you okay with having to pip3 install pyudev? I can add it to the instructions list.

I changed things so you can either fill out config.json and then run with python3 GUI.py --config, or you can just run the normal way, and it'll find things with ID_VENDOR that includes Arduino, Adafruit, or FTDI. Metro M0 boards seem to use Adafruit, but I wanted to be able to support other Arduino boards too. I tested with the Uno (Arduino), Mega (Arduino), and Nano (FTDI).

I haven't made it so it detects when you plug something in. I figured it was good enough to just make sure you plug things in before you start the GUI. But I can make it detect if you think it's useful. What do you think? I'm not sure what your use case is like.

streadgold, 2020-11-08:
Sure! Asynchronous device monitoring sounds great

dallasbrittany, 2020-11-18:
Yeah, it would really help if I could type correctly the first time.

This:
`NameError: name 'OPEN_SERIAL_PORT' is not defined`
happened because it's supposed to be plural. Sorry. Fixed now.

Closed 2020-11-21.

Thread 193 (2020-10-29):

One ard to mind them. One ard to sense them all and to their angles bind them.

juggler2000, 2020-10-29:
[flashback music] The original plan was always to have a single Arduino control all of the motors.  That's not what we're doing now.

The challenge here is that we have 10 DC motors, each with a dual-channel Hall-Effect sensors to track position.  These 20 signals must be read w/o missing a blip, or we will lose track of where we are.

Hardware interrupts were the only reliable method we found to do the sensing. Software interrupts would miss sometimes.  The trouble is, typical Arduinos only have a limited number of HW interrupts available.   Uno's have 2.  Mega's have 6. Others boards report that "any pin can be a HW interrupt" which is true, but you can only have so many in use at once (not very many).

We are currently using Adafruit's Metro M0 Express, which provides enough interrupts for 4 motors.  So we have three of these boards in use to cover our 10 DC motors (plus 2 servos).

The Artemis ATP (https://www.sparkfun.com/products/15442) may be promising for lotza HW interrupts, but so far we have not had time to dig deep into it.  When the board was first released, there wasn't support for the encoder library we use and a quick ask didn't yield results. https://forum.sparkfun.com/viewtopic.php?t=51850

Another option is to use a multiplexer to read all 20 signals and report status via I2C to an ard.  Looked into it, but haven't tried it.

This problem seems solvable!

Collateral damage:  If we succeed with a single Ard board, we'd have to change our custom HDMI (just for compact cabling -- not sending video) connector shields to have all connectors on a single board or stackable rather than the three shields (one on each Metro M0) that we currently use.  We would also need to stack our motor driver shields, which is not an issue.

*Issue title credit goes to SWGlassPit

juggler2000, 2021-12-02:
The Adafruit M4 boards, including the tiny Feather version, include more discrete interrupt pins.  Here's the M4 Feather pinout:
https://learn.adafruit.com/assets/101972

I think there are ~11 interrupt pins available to us that don't share a pin with a vital function (I2c communication, TX/RX, etc.).   So, this is not enough to cover the 20 interrupt pins we'd need to read encoders from all 10 DC motors, but we could possibly remove the SARJ/TRRJ Metro (TRRJs don't require encoders since driven by servos).

Or, we could cram these little M4 feathers plus motor controller FeatherWing shield into the outboard truss, so that only power and two serial data lines would have to go up the tree.  But, would make debugging harder.

juggler2000, 2024-01-10:
This will not be part of the current architecture.  If we replace the entire mechatronics approach (such as with Robotis motors if they produce a smaller one) then this will effectively be realized.

Closed 2024-01-10.

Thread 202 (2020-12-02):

Arduino Motor shields -- solderless solution

juggler2000, 2020-12-02:
To minimize complexity, we prefer our build to be possible without soldering.  This has mostly been achieved, but our beloved Adafruit motor shield v2.3 does not come with headers in place (and note that we need stackable headers, which is not what comes with it).  We also need to set one of the solder jumpers so that the board uses 3.3v logic instead of the default 5v. If we don't do this, we could fry some of the pins on our Arduino (or maybe even the entire board).

Since the board is open source (I think), one possibility is to make our own design of this board (in Gerber or similar), so that it could be ordered from a PCB manufacturer as an assembled, ready-to-go piece. We use three of these in our build.

Adafruit Motor Shield: https://www.adafruit.com/product/1438

streadgold, 2020-12-02:
Alternatively..... Combine the motor shield and hdmi shield into one design... Stretch goal

juggler2000, 2020-12-02:
Yea, that's even better. And that way we could have our own connectors for motor power, encoder power, sensor data returning, etc.  That would be very, very nice.

cactus314, 2021-07-28:
The current solution for reducing the soldering required for these shields is to use clones of the Adafruit motor shield off of Amazon: [HiLetgo Motor Shield](https://smile.amazon.com/HiLetgo-TB6612FNG-Stepper-Motor-Replace/dp/B073SP76MC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).
They come with the stacking headers already soldered in place, plus they're cheaper (we're just not supporting Adafruit).  Preparing them for use on the Adafruit Metro 0 (3.3V logic) is a 5-minute process once you have your tools together and iron heated up.  I'm preparing the documentation and video for the conversion steps.

SpaceTowel, 2021-08-11:
BOM updated with Motor Shield.  Shield is being tested.

Closed 2021-08-11.

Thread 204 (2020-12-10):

S3 Motor mount too thick for our standard screw length

juggler2000, 2020-12-10:
Can either use longer screws or countersink hole a bit.

juggler2000, 2021-08-12:
@Digisembler mentioned he'd update CAD/STL to reflect narrower width or countersunk holes to accommodate screws now listed in BOM, which are the same as used on prior prototype build.  Removing myself from this issue.

juggler2000, 2021-12-02:
@Digisembler , did you update the CAD per above?  We had the same issue for the PIRB build, but I wasn't sure if those were printed from a prior CAD version.

Closed 2023-12-09.

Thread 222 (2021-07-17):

Motor issue

streadgold, 2021-07-17:
We keep burning out metros on the starboard side. Due to issues turning the 3a motor manually I am guessing maybe there is a problem with that motor. Unknown of it is causing the metro to burn out

cactus314, 2021-07-18:
If it's always on the starboard side, have you also always been using the same motor driver shield?  It could be bad somehow.  I looked today and verified (visually and by probing) that the Vin jumper isn't shorted and that the 3.3V logic is properly bridged and the 5V logic connection is severed/isolated.  Not sure what else to check except just to swap it out and see if the Metros stop burning out.
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

juggler2000, 2021-08-01:
Maybe mark this driver board with a "sus" and replace it as @cactus314 suggested.

SpaceTowel, 2021-08-04:
Replace Motor shield?   Patrick to Test Motor shield on an isolated Arduino/board.
Slip ring?  ways to debug?
Very hot at the voltage regulator at time of burn out, no LED (aka, no 5V).   hook up leads to burn board to see if it still regulate voltage.
Sam to ask electrical specialist on ways to figure out how to troubleshoot.

cactus314, 2021-08-06:
@streadgold - Just to verify, this is the component that is getting hot on the Metro 0, correct?  I may throw a thermocouple on it while measuring various motor currents from the motor shield to see if there's a correlation to any specific BGA motor on the starboard side,
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

streadgold, 2021-08-06:
I believe so. Was in that area for sure

cactus314, 2021-08-06:
@juggler2000 @streadgold
Spent some hours debugging the motor situation today.  tl;dr:  ¯\_(ツ)_/¯

- free-running geared motor out of the box pulls ~65mA at 12VDC; ~95mA when finger pressure is applied to the shaft (not stall)
- Prepared the Arduino IDE for the Metro 0 chipset, including loading the encoder.h library (hopefully the correct one).  Tested by loading a 'blink' sketch to a new Metro 0 and everything worked, so I pulled the Ard_StbdBGAs_r18 .ino files and uploaded them to the Metro 0.
- Taped a small thermocouple to the power regulator chip on the Metro to see if I could monitor/identify thermal effects.  **NOTE**: During the course of these tests, the maximum temperature increase was 1degC, so I didn't register any thermal failures.
- Used the 'old' motor shield and Mimic shield as rewired when the STEM Mimic was brought to my house.  One lead from each motor was disconnected from the Mimic shield to prevent any motors from turning when power was applied to the shield.
- Connected the Metro 0 to the proper USB cable, applied 12VDC to the motor shield, but did not begin to run GUI.py
- As soon as I put a current meter in series with Mimic Shield M1, BGA 3B began turning.  Current draw was ~60mA.
- Tested Mimic Shield M2, BGA 1B began turning.  Current draw was 65-73mA.
- Tested Mimic Shield M3 - no spontaneous motion of any BGA motors.  Ran GUI.py, but was unable to cause any BGA motion on the starboard side.  (Port side appeared to respond appropriately.)
- Closed GUI.py, tested Mimic Shield M4, BGA 1A spontaneously turns.  Current draw ~60mA.  Noticed two of the Neopixels on the 1A IEA board were on.
- Since the Mimic Shield M3 connections didn't cause motion (presumably of BGA 3A), I moved those connections to Mimic Shield M4, but this caused BGA 1A to spontaneously begin turning again.  Curious.
- So, plugged all motors back into original positions, GUI.py not running.  BGAs 1A & 3B rotate, 1B oscillates, 3A static.  By running GUI.py, it seems like I can cause small temporary motion changes to the BGAs, but then they resume previous motion.  I cannot get 3A to move.  BGA 1A reversed direction during this portion of the test.
- Disconnected the USB cable from the Metro 0 and powered the Metro via 9VDC on the barrel jack.  This was to prevent any spurious serial data that might have been coming in over the USB.  Similar spontaneous behavior as before, though.
- Installed a new motor shield (modified for 3.3V logic).  Similar spontaneous behavior.
- Uploaded a 'null-code' for firmware onto the Metro 0.  No response from motors.  Reinstalled Ard_StbBGA_r18 and behavior resumed.

At this point, I don't know if this is a software issue or maybe a bad Mimic shield?  I intend to swap out the Mimic shield with one of the new ones that I got in from JLCPCB, but I'd like to know what the status LEDs mean.  But this feels like software and I'm kinda afraid it's something simple like my not using the IDE properly.  In any case, I couldn't diagnose any reasons for killing Metros on the starboard side, I just observed weird behavior.

If you've read this far, congratulations.  Thoughts and advice appreciated.

cactus314, 2021-08-07:
Checked coil resistances of motors this morning:
Out of the box, geared motor resistance ~ 19 Ohms
Measured across Mimic Shield M1: 19 Ohms
Measured across Mimic Shield M2: 14 Ohms
Measured across Mimic Shield M3: Open circuit
Measured across Mimic Shield M4: 19 Ohms

Isolated BGA Motor 3A using a separate breakout board (one of the new ones).  Motor coil resistance: ~34 Ohms.  Applied 12VDC, and the motor turned, pulling 130-150 mA (compared to ~60 mA for the other motors).

So there appears to be a break in the BGA 3A circuit, and the motor might be failing.  My eyesight is getting worse, so even with glasses I was unable to test the existing HDMI breakout board to see if the problem was there, and I don't know the pinout of the existing IEA breakout board to test anything there - plus the whole eyesight thing.  I need new glasses and/or a hand-held magnifier.

cactus314, 2021-08-14:
Troubleshooting update:

- "Jiggling" the 1A/3A HDMI breakout board fixed the open circuit on BGA 3A and now reads 19Ohms through the motor coil
- The starboard Arduino Motor Shield Stack had been installed and labled backwards when delivered (i.e., 1B/3B HDMI running to 1A/3A BGA motors)
- Error in the Serial Output debug section of the Ard_StdbBGAs_r18 code for displaying the proper encoder output - fixed locally, but not uploaded to GH yet
- The exisiting Mimic Shield was replaced with one of the new Mimic Shields from my July order in the orientation specified by the silkscreen and the encoders responded appropriately to manual rotation of the individual motors
- The motors were wired according to the silkscreen on the Mimic Shield, but the erratic motor rotations/oscillations continuted (presummed mismatch between motor output and encoder feedback)
- Motors re-wired to match motors to appropriate encoders (Motor Shield M1-> Mimic Shield M2; Motor Shield M2->Mimic Shield M1; Motor Shield M3->Mimic Shield M4; Motor Shield M4->Mimic Shield M3)
- Now on power-up, all BGAs respond with appropriate initialization move and then stop, though there is some slight hum from at least one motor.
- Was going to test the motor control from the RPi GUI, but the display won't come on.  Opening a ticket for that and will troubleshoot it next (likely a loose connection in the display ribbon cable?)
- I have not yet changed out motor 3A as @streadgold requested.  I'll do that soon.

@streadgold - Not sure if there is a problem with the Mimic Shield or somewhere in the HDMI breakouts that is requiring me to swap the motor connections.  Also, there appears to be a problem (intermittent) with the 1A/3A HDMI breakout board causing open circuits.

**Finally, none of this necessarily explains why starboard Metro BGA controllers keep failing.**

juggler2000, 2021-08-15:
oof.

Had any similar wire tracing issues on the port side?

cactus314, 2021-08-15:
@juggler2000 - The port side has been working like a champ (BGAs & IEA Neopixels) ever since it has arrived here at my place.  Now I've probably jinxed it...

SWGlassPit, 2021-11-15:
Update: putting a scope on the assembly shows that the 3.3v rail is getting pulled down to -0.8v (!) at the precise moment the motor lines get energized. This happens even when the HDMI cables (including the motors) are disconnected. Sending 3v3 below ground would certainly fry the regulator or microcontroller. Appears to be capacitive coupling somewhere.

Additional troubleshooting steps to try:
 [ ] Verify whether this effect is isolated to the 3.3v rail or whether the 5v rail is affected as well
 [ ] Determine if the effect persists when the wires from the motor driver shield to the mimic shield are disconnected (i.e., is the coupling in the traces of the mimic shield or elsewhere?)
 [ ] If yes, does the effect persist when the mimic shield is removed entirely?
 [ ] Else, is the effect in any way related to the loose wires between the motor shield and the mimic shield? Does twisting them help?

Potential workarounds:
 - additional bypass capacitors on mimic shield between power rails and ground
 - adjust wire routing (and possibly HDMI pinout) to keep ground traces between motor traces and power rails
 - add reverse bias protection diodes (or some other solution) between power rails and ground to keep the reverse polarity clipped to reasonable levels. Schottky diodes will limit to -0.3v. (note this may be a red herring -- while reverse polarity protection isn't a bad idea, far better to eliminate the source if possible)

ISS-Mimic, 2021-11-16:
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

@SWGlassPit Yeah the 3V and 5V lines are in the adjacent pins to one of the motors. I wonder if disconnecting the motor that runs next to those pins and then scoping the other motor and 3V would clue us into if the HDMI pin selections is the issue?

SWGlassPit, 2021-11-16:
That's not a ton of overlap between traces. I'm wondering if the behavior
exists if we pull the mimic shield off but leave the motor shield on

On Mon, Nov 15, 2021, 20:29 ISS Mimic Project ***@***.***>
wrote:

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

SWGlassPit, 2021-11-17:
Another possibility I had not previously considered may be that the motor driver is pulling ground up instead of the rails down if our grounding strategy tying the two together is ill advised.

juggler2000, 2022-11-30:
Since it hasn't happened in a year, we must have fixed it! :P  Closing issue to tempt fate.

Closed 2022-11-30.

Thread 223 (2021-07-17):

Import and Runtime errors with numpy and missing 'service_identity' module

cactus314, 2021-07-17:
After manually installing the Mimic software (mostly following the Wiki guide), the following errors show on exit:pi@raspberrypi:~/Mimic/Pi $ python3 GUI.py
[INFO   ] [Logger      ] Record log in /home/pi/.kivy/logs/kivy_21-07-17_6.txt
[INFO   ] [Kivy        ] v2.0.0
[INFO   ] [Kivy        ] Installed at "/home/pi/.local/lib/python3.7/site-packages/kivy/__init__.py"
[INFO   ] [Python      ] v3.7.3 (default, Jan 22 2021, 20:04:44)
[GCC 8.3.0]
[INFO   ] [Python      ] Interpreter at "/usr/bin/python3"
[INFO   ] [Factory     ] 186 symbols loaded
[INFO   ] [Image       ] Providers: img_tex, img_dds, img_sdl2, img_pil (img_ffpyplayer ignored)
[INFO   ] [Text        ] Provider: sdl2(['text_pango'] ignored)
Mimic Directory: /home/pi
Serial ports opened: []
Started monitoring serial ports.
[INFO   ] [Window      ] Provider: sdl2
[INFO   ] [GL          ] Using the "OpenGL" graphics system
[INFO   ] [GL          ] Backend used <gl>
[INFO   ] [GL          ] OpenGL version <b'2.1 Mesa 19.3.2'>
[INFO   ] [GL          ] OpenGL vendor <b'Broadcom'>
[INFO   ] [GL          ] OpenGL renderer <b'V3D 4.2'>
[INFO   ] [GL          ] OpenGL parsed version: 2, 1
[INFO   ] [GL          ] Shading version <b'1.20'>
[INFO   ] [GL          ] Texture max size <4096>
[INFO   ] [GL          ] Texture max units <16>
[INFO   ] [Window      ] auto add sdl2 input provider
[INFO   ] [Window      ] virtual keyboard not allowed, single mode, not docked
[INFO   ] [Clipboard   ] Provider: xclip
[INFO   ] [CutBuffer   ] cut buffer support enabled
[INFO   ] [GL          ] NPOT texture support is available
[INFO   ] [Loader      ] using a thread pool of 2 workers
[INFO   ] [ProbeSysfs  ] device match: /dev/input/event3
[INFO   ] [MTD         ] Read event from </dev/input/event3>
[INFO   ] [ProbeSysfs  ] device match: /dev/input/event1
[INFO   ] [MTD         ] Read event from </dev/input/event1>
[INFO   ] [ProbeSysfs  ] device match: /dev/input/event4
[INFO   ] [MTD         ] Read event from </dev/input/event4>
[INFO   ] [ProbeSysfs  ] device match: /dev/input/event2
[INFO   ] [MTD         ] Read event from </dev/input/event2>
[INFO   ] [ProbeSysfs  ] device match: /dev/input/event0
[INFO   ] [MTD         ] Read event from </dev/input/event0>
[INFO   ] [ProbeSysfs  ] device match: /dev/input/event3
[INFO   ] [HIDInput    ] Read event from </dev/input/event3>
[INFO   ] [ProbeSysfs  ] device match: /dev/input/event1
[INFO   ] [HIDInput    ] Read event from </dev/input/event1>
[INFO   ] [ProbeSysfs  ] device match: /dev/input/event4
[INFO   ] [HIDInput    ] Read event from </dev/input/event4>
[INFO   ] [ProbeSysfs  ] device match: /dev/input/event2
[INFO   ] [HIDInput    ] Read event from </dev/input/event2>
[INFO   ] [ProbeSysfs  ] device match: /dev/input/event0
[INFO   ] [HIDInput    ] Read event from </dev/input/event0>
[INFO   ] [Base        ] Start application main loop
[INFO   ] [MTD         ] </dev/input/event3> range position X is 0 - 0
[INFO   ] [MTD         ] </dev/input/event3> range position Y is 0 - 0
[INFO   ] [MTD         ] </dev/input/event1> range position X is 0 - 0
[INFO   ] [MTD         ] </dev/input/event4> range position X is 0 - 799
[INFO   ] [MTD         ] </dev/input/event3> range touch major is 0 - 0
[INFO   ] [MTD         ] </dev/input/event1> range position Y is 0 - 0
[INFO   ] [MTD         ] </dev/input/event2> range position X is 0 - 0
[INFO   ] [MTD         ] </dev/input/event4> range position Y is 0 - 479
[INFO   ] [MTD         ] </dev/input/event0> range position X is 0 - 0
[INFO   ] [MTD         ] </dev/input/event3> range touch minor is 0 - 0
[INFO   ] [HIDMotionEvent] using <mini keyboard Consumer Control>
[INFO   ] [MTD         ] </dev/input/event1> range touch major is 0 - 0
[INFO   ] [HIDMotionEvent] using <mini keyboard Mouse>
[INFO   ] [MTD         ] </dev/input/event2> range position Y is 0 - 0
[INFO   ] [HIDMotionEvent] using <raspberrypi-ts>
[INFO   ] [MTD         ] </dev/input/event4> range touch major is 0 - 0
[INFO   ] [MTD         ] </dev/input/event0> range position Y is 0 - 0
[INFO   ] [HIDMotionEvent] using <mini keyboard System Control>
[INFO   ] [HIDMotionEvent] using <mini keyboard>
[INFO   ] [MTD         ] </dev/input/event3> range pressure is 0 - 255
[INFO   ] [MTD         ] </dev/input/event0> range touch major is 0 - 0
[INFO   ] [MTD         ] </dev/input/event1> range touch minor is 0 - 0
[INFO   ] [MTD         ] </dev/input/event3> axes invertion: X is 0, Y is 0
[INFO   ] [MTD         ] </dev/input/event4> range touch minor is 0 - 0
[INFO   ] [MTD         ] </dev/input/event2> range touch major is 0 - 0
[INFO   ] [MTD         ] </dev/input/event0> range touch minor is 0 - 0
[INFO   ] [HIDMotionEvent] <raspberrypi-ts> range ABS X position is 0 - 799
[INFO   ] [MTD         ] </dev/input/event1> range pressure is 0 - 255
[INFO   ] [MTD         ] </dev/input/event3> rotation set to 0
[INFO   ] [MTD         ] </dev/input/event4> range pressure is 0 - 255
[INFO   ] [MTD         ] </dev/input/event2> range touch minor is 0 - 0
[INFO   ] [MTD         ] </dev/input/event0> range pressure is 0 - 255
[INFO   ] [HIDMotionEvent] <raspberrypi-ts> range ABS Y position is 0 - 479
[INFO   ] [MTD         ] </dev/input/event1> axes invertion: X is 0, Y is 0
[INFO   ] [MTD         ] </dev/input/event4> axes invertion: X is 0, Y is 0
[INFO   ] [MTD         ] </dev/input/event2> range pressure is 0 - 255
[INFO   ] [MTD         ] </dev/input/event0> axes invertion: X is 0, Y is 0
[INFO   ] [HIDMotionEvent] <raspberrypi-ts> range position X is 0 - 799
[INFO   ] [MTD         ] </dev/input/event1> rotation set to 0
[INFO   ] [MTD         ] </dev/input/event4> rotation set to 0
[INFO   ] [MTD         ] </dev/input/event2> axes invertion: X is 0, Y is 0
[INFO   ] [MTD         ] </dev/input/event0> rotation set to 0
[INFO   ] [HIDMotionEvent] <raspberrypi-ts> range position Y is 0 - 479
[INFO   ] [MTD         ] </dev/input/event2> rotation set to 0
ISS Telemetry script active
DISCONNECTED
:0: UserWarning: You do not have a working installation of the service_identity module: 'No module named 'service_identity''.  Please install it from <https://pypi.python.org/pypi/service_identity> and make sure all of its dependencies are satisfied.  Without the service_identity module, Twisted can perform only rudimentary TLS client hostname verification.  Many valid certificate/hostname mappings may be rejected.
Client status:CONNECTING
Client status:CONNECTED:STREAM-SENSING
Client status:CONNECTED:WS-STREAMING
Subscribed
Signal Error!     @ 4773.18058805552
RuntimeError: module compiled against API version 0xe but this version of numpy is 0xd
Traceback (most recent call last):
  File "/home/pi/Mimic/Pi/NightShade.py", line 1, in <module>
    import matplotlib as mpl
  File "/home/pi/.local/lib/python3.7/site-packages/matplotlib/__init__.py", line 107, in <module>
    from . import _api, cbook, docstring, rcsetup
  File "/home/pi/.local/lib/python3.7/site-packages/matplotlib/rcsetup.py", line 26, in <module>
    from matplotlib.colors import Colormap, is_color_like
  File "/home/pi/.local/lib/python3.7/site-packages/matplotlib/colors.py", line 82, in <module>
    from matplotlib import _api, cbook, scale
  File "/home/pi/.local/lib/python3.7/site-packages/matplotlib/scale.py", line 18, in <module>
    from matplotlib.ticker import (
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
ISS-Mimic, 2021-07-20:
@cactus314 try "pip3 install --upgrade numpy" and see if the error returns

cactus314, 2021-07-22:
I couldn't recreate the error on my second (more successful) installation attempt.  When/if I try booting off the other MicroSD card again I will try this.  Otherwise, you can consider closing this issue.

cactus314, 2021-08-04:
I was using my "clean" install and got the numpy import error (must happen from some specific GUI window or sequence), so I tried the upgrade as recommended.  That killed everything and now GUI.py is fully broken.  See output below.  I'm going to redo the installation.
>>>>>>>>>>

pip3 install --upgrade numpy
/usr/lib/python3/dist-packages/secretstorage/dhcrypto.py:15: CryptographyDeprecationWarning: int_from_bytes is deprecated, use int.from_bytes instead
  from cryptography.utils import int_from_bytes
/usr/lib/python3/dist-packages/secretstorage/util.py:19: CryptographyDeprecationWarning: int_from_bytes is deprecated, use int.from_bytes instead
  from cryptography.utils import int_from_bytes
Defaulting to user installation because normal site-packages is not writeable
Looking in indexes: https://pypi.org/simple, https://www.piwheels.org/simple
Requirement already satisfied: numpy in /usr/lib/python3/dist-packages (1.16.2)
Collecting numpy
  Downloading https://www.piwheels.org/simple/numpy/numpy-1.21.1-cp37-cp37m-linux_armv7l.whl (12.3 MB)
     |\u2588\u2588\u2588\u2588\u2588\u2588\u2588\u2588\u2588\u2588\u2588\u2588\u2588\u2588\u2588\u2588\u2588\u2588\u2588\u2588\u2588\u2588\u2588\u2588\u2588\u2588\u2588\u2588\u2588\u2588\u2588\u2588| 12.3 MB 4.8 kB/s
Installing collected packages: numpy
Successfully installed numpy-1.21.1
WARNING: You are using pip version 21.1.3; however, version 21.2.2 is available.
You should consider upgrading via the '/usr/bin/python3 -m pip install --upgrade pip' command.
pi@raspberrypi:~/Mimic/Pi $ python3 GUI.py
Traceback (most recent call last):
  File "/home/pi/.local/lib/python3.7/site-packages/numpy/core/__init__.py", line 22, in <module>
    from . import multiarray
  File "/home/pi/.local/lib/python3.7/site-packages/numpy/core/multiarray.py", line 12, in <module>
    from . import overrides
  File "/home/pi/.local/lib/python3.7/site-packages/numpy/core/overrides.py", line 7, in <module>
    from numpy.core._multiarray_umath import (
ImportError: libf77blas.so.3: cannot open shared object file: No such file or directory

During handling of the above exception, another exception occurred:

Traceback (most recent call last):
  File "GUI.py", line 13, in <module>
    import numpy as np
  File "/home/pi/.local/lib/python3.7/site-packages/numpy/__init__.py", line 150, in <module>
    from . import core
  File "/home/pi/.local/lib/python3.7/site-packages/numpy/core/__init__.py", line 48, in <module>
    raise ImportError(msg)
ImportError:

IMPORTANT: PLEASE READ THIS FOR ADVICE ON HOW TO SOLVE THIS ISSUE!

Importing the numpy C-extensions failed. This error can happen for
many reasons, often due to issues with your setup or how NumPy was
installed.

We have compiled some common reasons and troubleshooting tips at:

    https://numpy.org/devdocs/user/troubleshooting-importerror.html

Please note and check the following:

  * The Python version is: Python3.7 from "/usr/bin/python3"
  * The NumPy version is: "1.21.1"

and make sure that they are the versions you expect.
Please carefully study the documentation linked above for further help.

Original error was: libf77blas.so.3: cannot open shared object file: No such file or directory

SpaceTowel, 2021-08-04:
check the version of NumPy that encountered the error.

cactus314, 2021-08-18:
@streadgold - Per recommendations at: https://numpy.org/devdocs/user/troubleshooting-importerror.html#raspberry-pi
I tried:
`sudo apt-get install libatlas-base-dev`
which fixed the numpy error and allowed GUI.py to run as normal without error.  This seems like a clean fix, but I'm not sure I should have upgraded numpy to begin with?  Consider closing this issue if you want.

streadgold, 2021-08-18:
Still disconcerting that upgrading numpy caused so much trouble but oh well.

I've added the apt install option to the software install page

cactus314, 2021-08-18:
@streadgold : The alternative solution was to use the Raspbian version of numpy:
```
pip3 uninstall numpy  # remove previously installed version
apt install python3-numpy
```

streadgold, 2021-08-18:
Yep that's what I used, I like the apt install option best

Closed 2021-08-18.

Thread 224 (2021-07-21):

Problems following Wiki Instructions for Mimic software on RPi

cactus314, 2021-07-21:
On 16 July 2021 I tried an installation of the Mimic software following the "Mimic Software Setup Instructions" on the Wiki - Option 2: Setup from Scratch.  I started with a new 32GB microSD card from the BOM using a fresh image of the Raspberry Pi OS.  Here are some observations and problems I ran into.

- Somewhere (maybe during the repository cloning?) the directory ~/MIMIC/ was created instead of ~/Mimic/.  Not sure how or why this happened, but I don't think I did it manually.
- For Step 4 (Install npm), I couldn't get the curl command to work.  Based on a suggestion from the Discord discussion, I tried "curl -sL https://deb.nodesource.com/setup_16.x | sudo -E bash -" and that worked.  Or at least it seemed to.
- For Step 10 (Install Kivy), I had to insert the word "install" before --upgrade and --user in the three python3 commands
- The Wiki implies to me that only a couple of lines in the ~/.kivy/config.ini file need to be modified for the interface to work.  But I had to replace the whole file with the Mimic version in order for the GUI screen to scale properly
- There were import errors from numpy when exiting the program
- There was a runtime error ("module compiled against API version 0xe but this version of numpy is 0xd") when exiting the program
- Warnings during the installations of one or more of the packets (I don't recall which ones) implied that I should add ~/.local/bin to PATH (which I added in ~/.profile)
- When running the Mimic GUI, the telemetry didn't work.  Sam did something (maybe repeated "npm install sqlite3"?) and the telemetry began working.

I intend to repeat the installation process again with another fresh image of the RPi OS and see if I can replicate these errors.

cactus314, 2021-07-22:
I repeated the installation procedure on 21 July using a new MicroSD card with a fresh RPi image and followed the same software setup instructions from the Wiki as before.  Many of the errors/issues did not repeat - I don't know how much can be attributed to user error during my first attempt.  Here are the highlights:

- The curl call specified in Step 4 worked this time.
- No errors with numpy.
- Telemetry worked straight away after the installation procedure.
- **Still needed to include the command "install" in Step 10**
- Got the warnings about adding ~/.local/bin to PATH, but this time there was already code in ~/.profile to address this.  Not sure why this wasn't there in the first installation.
- I didn't try manually modifying the ~/.kivy/config.ini file this time.  I simply replaced it with the one pulled from the Mimic repository.

cactus314, 2021-08-04:
Ran a third clean installation - this time using the setup.py script.  Everything seems okay for telemetry (though I don't have the RPi hooked up to a Mimic model to test control) and the errors aren't repeatable.  Recommend @streadgold closes this Issue, but I'm opening a new one regarding the Kivy installation.

Closed 2021-08-08.

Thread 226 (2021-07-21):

Add Micro gear dc motor screws to BOM

Digisembler, 2021-07-21:
Went to go fix the S3 motor mount issue #204 and didn't have the nominal screw length, and it needs to be added to the BOM regardless

juggler2000, 2021-08-11:
M1.6x 0.35, 5mm length, hex head. Will look for a vendor.

juggler2000, 2021-08-12:
This seems like a good option. Countersunk, with torx head. https://www.mcmaster.com/92703A142

cactus314, 2021-08-12:
> This seems like a good option. Countersunk, with torx head. https://www.mcmaster.com/92703A142

Do the outboard truss pieces also need to be modified to accommodate that countersink?
Should I order some and try them on my build before adding them to the BOM?

juggler2000, 2021-08-12:
Utilized same screws as ordered for PIRB unit.  Updated BOM to add item and reflect updated costs.

Closed 2021-08-12.

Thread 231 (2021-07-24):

Changes to Frame BOM

cactus314, 2021-07-24:
The Frame BOM calls for 3 packages of 2020 rubber feet (4 per package, 9 total required).  However, only 8 rubber feet are required.  The central rear support doesn't use a rubber foot because the 50mm rod support is flush with the end of the 2020 extrusion and there's no room for the foot to slip on.
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

Instead, the BOM should call for 2 packages of 2020 rubber feet (8 total required) and one package of [2020 endcaps](https://www.zyltech.com/2020-end-cap-cover-10-pack/).  This is a package of ten and might be overkill to spend $4.45 for a single needed part, so we could offer a 3D-printed alternative.  The printed endcap on the left is from Thingiverse ([Thing 813368](https://www.thingiverse.com/thing:813368)) and fits quite snug.  The purchased part is on the right.  The printed part in the center, also from Thingiverse, doesn't fit very tight.
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

juggler2000, 2021-08-01:
Printed version looks sufficient to me.  We can have that as the primary plan, with purchased 10-pack of caps as the backup.

Closed 2021-08-03.

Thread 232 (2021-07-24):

Errors in the detailed frame build guide

cactus314, 2021-07-24:
I finally built out the Mimic frame following the detailed build guide and found a few details which aren't consistent with the current STEM model and frame BOM.  Most notably, the guide calls for small L-brackets in many places where large brackets are used.  There are also some discrepancies (known and noted in the guide) in the dimensions between the vertical elements of the frame.  I took a number of photos during the build process and can take more of the finished frame (without all the cabling, etc.) as required.  The photos are currently on a GoogleDrive, but I can share them in whatever way is best.  I'm happy to help edit the build guide in whatever capacity in order to make it current and consistent with the STEM model and future builds.
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

Digisembler, 2021-07-24:
Thanks @cactus314 !  I was noticing on the 2nd build we're working on that we might end up with side mounted L brackets to help stiffen the short vertical pieces holding up the pressurized modules, as ours are pretty floppy. Cannot use T plates as they're too close to the main central brackets.  I think we also had to remove the back central bracket to get correct spacing between the node 1 and node 2 vertical mount rods. Let us know how it comes along for you please!

juggler2000, 2024-02-01:
This one is now redundant to this: https://github.com/ISS-Mimic/Mimic/issues/512 .

Also, ppt from 2022 seems to have all the of the updates: Wiki/Mimic One Frame Updated.pptx

Closed 2024-02-01.

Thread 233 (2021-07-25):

Error in Pre-Assembled PCB costing

cactus314, 2021-07-25:
The sub-total listed for the (mostly) pre-assembled PCBs under [Custom Printed Circuit Boards (PCBs) - Assembled](https://github.com/ISS-Mimic/Mimic/wiki/Build-Instruction%3A-Bill-of-Materials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) appears to be for the boards from JLCPCB only and doesn't include the extra parts needed from Amazon to be soldered to the underside of the boards - should be an extra $26.78 or so.  This might impact the [final totals](https://github.com/ISS-Mimic/Mimic/wiki/Build-Instruction%3A-Bill-of-Materials#mimic-total-cost) below as well - I didn't check.

SupaTreadz, 2021-07-25:
ah! good catch thanks

streadgold, 2021-07-25:
ah! good catch, thanks

streadgold, 2021-07-25:
Also added HDMI cable cost, now the pre-assembled are more expensive than DIY

Closed 2021-07-25.

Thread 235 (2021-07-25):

Potential double listing of motor connectors in the BOM

cactus314, 2021-07-25:
It looks to me like the [motor connectors](https://www.amazon.com/1-5MM-Female-Double-Connector-Cable/dp/B07HSZJ2PM/) (which are ordered along with associated wiring) are listed both under [Essential Parts](https://github.com/ISS-Mimic/Mimic/wiki/Build-Instruction%3A-Bill-of-Materials#essential-parts) and also listed in the [DIY PCB](https://github.com/ISS-Mimic/Mimic/wiki/Build-Instruction%3A-Bill-of-Materials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) section.  These are only required if you're building your own boards from scratch (i.e., not ordering pre-fab boards) and should be removed from the "Essential Parts" list, correct?
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

streadgold, 2021-07-25:
yep. look who just saved us $7.99

Closed 2021-07-25.

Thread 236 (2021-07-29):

Changes/Additions to the Raspberry Pi / Mimic Control Unit BOM

cactus314, 2021-07-29:
Need to add/change the following to the [RPi BOM](https://github.com/ISS-Mimic/Mimic/wiki/Build-Instruction%3A-Bill-of-Materials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):

1. Consider changing the recommended CanaKit power supply to [this one](https://smile.amazon.com/gp/product/B097P2NLVH/ref=ppx_yo_dt_b_search_asin_title?ie=UTF8&psc=1) (Amazon) from iUniker.  It has the same voltage/current specs and price but includes a power switch.
2. Add [Sabrent 4-Port USB Hub](https://smile.amazon.com/gp/product/B00TPMEOYM/ref=ppx_yo_dt_b_search_asin_title?ie=UTF8&psc=1) (Amazon)
3. Add 4 [USB-A to USB-Micro (3-ft) cables](https://smile.amazon.com/gp/product/B011KLFERG/ref=ppx_yo_dt_b_search_asin_title?ie=UTF8&psc=1) (Amazon), or suggest digging some out of the surplus cable box most people seem to have sitting around.  Must be data cables - not just charging cables.  These connect from the USB hub to the Metro 0's (motors) and to the Metro Mini (Neopixels).

juggler2000, 2021-08-01:
I agree with these suggestions.  @cactus314, feel free to make the updates and clos this issue when ready.  Thanks.

Closed 2021-08-03.

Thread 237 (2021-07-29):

Changes/Additions to the "Essential Parts" BOM

cactus314, 2021-07-29:
Suggested changes/additions to the [Essential Parts](https://github.com/ISS-Mimic/Mimic/wiki/Build-Instruction%3A-Bill-of-Materials#essential-parts) BOM:

1. The [Traxxas 3942 pinion gear](https://www.amazon.com/gp/product/B0006O5L1S/) is no longer available and has been superseded by the [Traxxas 3942X](https://www.amazon.com/Traxxas-3942X-Hardened-12-Tooth-Pinion/dp/B078KFCN72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) (Amazon).
2. Change the Adafruit Motor Shield to the [HiLetgo Motor Shield](https://www.amazon.com/gp/product/B073SP76MC/ref=ppx_yo_dt_b_search_asin_title?ie=UTF8&psc=1) (Amazon) which has the stacking header pins already installed (and is cheaper).  This shield still requires modifications to convert to 3.3V logic.
3. Need to add [M3 threaded rod](https://www.grainger.com/product/FABORY-Fully-Threaded-Rod-25DM75) (1-meter, 2 each required) from Grainger to the BOM.  These are used for supporting the inboard truss sections.
4. Add [M3 nylocks](https://www.lowes.com/pd/Hillman-8-Count-3mm-Zinc-Plated-Metric-Nylon-Insert-Lock-Nuts/999996650) (4 required).  Probably cheapest to get them from a local Lowes/Home Depot/Ace for such a small qty.
5. Add [velcro cable straps](https://smile.amazon.com/gp/product/B00O9VKVFK/ref=ewc_pr_img_1?smid=A2UV2VXDDFSPSW&psc=1) (Amazon) - optional, but nice for cable management.
6. Consider replacing the [recommended jumper wires](https://www.amazon.com/EDGELEC-Breadboard-Optional-Assorted-Multicolored/dp/B07GD2RP9C/) (all pin-to-pin) with a package that also includes pin-to-socket jumpers that can be used with the Neopixels.  [This package](https://smile.amazon.com/gp/product/B01EV70C78/ref=ppx_yo_dt_b_asin_title_o01_s01?ie=UTF8&psc=1) is an option (Amazon), but the jumpers are only 20cm instead of 30cm as stated in the recommended BOM version.  I don't know how big a problem that would be when wiring the motor shields to the Mimic Shields.
7. Need to add a [Metro Mini](https://smile.amazon.com/Adafruit-Metro-Mini-328-5V-16MHz/dp/B016RBLUZE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) (or some other Arduino) for controlling the Neopixels.

juggler2000, 2021-08-01:
1. Unfortunately the new gear is almost 2x the price of the old one.  But I haven't looked for another option.  This is fine since we only use two.
2. Agree.
3-4: Might be nice to use either Grainger or McMaster for the specialty smooth and threaded rods, rather than buying from both.  Could also include the M3 nylocks as an option there, as they seem to be available for <$4 for 50, the smallest quantity I saw.   Priced similar at Amazon, but cannot get the desired rods there.
5. Yes!
6. The current custom PCB Shield requires routing across the board to reach the proper screw terminals on the Motor Shield.   It seems like we are using pretty much all of the length of the current jumpers, but perhaps you can measure to confirm.
7. Metro Mini is fine with me.  Whatever board we use, just need to ensure we don't accidently send 5V to any 3V boards.  I think we could still run the Mini at the default 5V logic, but just need to double check this stuff.  5V preferred for LED power so we can go brighter, of course.  But I think that the IEAs (by theBGAs), we borrow 3V for the LEDs so those will be a bit dimmer.

cactus314, 2021-08-02:
Item 1: Not to quibble, but looking at the [existing BOM](https://github.com/ISS-Mimic/Mimic/wiki/Build-Instruction%3A-Bill-of-Materials#essential-parts), I think the price difference is only $1.19 each.

Item 3: Can't get the smooth rod from Grainger in a 2-ft length, and if we want the threaded rod to be stainless, it's cheaper (when considering shipping) to source two suppliers and order the threaded rods from Grainger.  I suggest that we go with [unplated steel from McMaster](https://www.mcmaster.com/98861A040/) for the M3 threaded rod since it shouldn't be exposed to the elements, then the 2-ft 3/16" rods, M3 threaded rods and M3 nylocks can all come from McMaster and get us the cheapest price when shipping is considered.  We just sacrifice the stainless material choice for the all-thread.

Item 6: I found a multi-pack with 30cm jumpers.  I do agree with you that you need the full 30cm for the motor hookups.  So long as you don't need more than 40 pin-to-pin jumpers total, [this pack](https://www.amazon.com/EDGELEC-Optional-Breadboard-Assorted-Multicolored/dp/B07GD2PGY4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) from Amazon should work, and includes the required socket jumpers for the Neopixel connections on the Mimic shield as well.

Item 7:  I thought you were already using a 5V-logic Arduino for the Neopixels.  I don't know for sure because that setup didn't make it to my house during the rapture, so I can't inspect the way y'all had the Neopixels hooked up except to know that they're getting power from the 3.3V Metro boards along with the encoders.  Using 5V logic and 3.3V power doesn't seem to be a problem so far as I can tell from a cursory Google search.

juggler2000, 2021-08-02:
1) agree.
3) okay!  sounds good.
6) Sweet.
7) You are right.... obviously it was 5V logic  (in hindsight) since we were using a Mega and a Pro Mini.

Closed 2021-08-03.

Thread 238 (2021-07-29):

Additions to the BOM for motor power

cactus314, 2021-07-29:
Not sure which section of the BOM these should go in, but they are required for supplying power to the motor shields (and thus the BGAs and SARGs).  It's not quite the same setup as what Bryan put together - I think it's a little cleaner by using a splitter.

1. [LEDO 12V/5A Power Supply](https://smile.amazon.com/gp/product/B01461MOGQ/ref=ppx_yo_dt_b_asin_title_o06_s01?ie=UTF8&psc=1) (Amazon)
2. [JEEUE 12V Power DC Male to Female Cable with On/Off Switch](https://smile.amazon.com/gp/product/B08SJQ8BXD/ref=ppx_yo_dt_b_asin_title_o06_s00?ie=UTF8&psc=1) (Amazon) - optional
3. [DZYDZR 3pcs 5.5mm x 2.1mm Y Splitter Cable 1 Female to 3 Male Splitter](https://smile.amazon.com/gp/product/B06Y5G3CMJ/ref=ppx_yo_dt_b_asin_title_o06_s00?ie=UTF8&psc=1) (Amazon) - package of 3, one required.
4. [DC Power Plug Pigtail Cable (Female Power Plug Pigtail Cable / 19.68 inches/Pack of 10)](https://smile.amazon.com/gp/product/B01M0EAR9N/ref=ppx_yo_dt_b_asin_title_o06_s00?ie=UTF8&psc=1) (Amazon) - only three of the pigtails will be used.

EDITED: Changed line item 4 to longer pigtails

juggler2000, 2021-08-01:
1. Suggested unit is fine, but this is what we'd been using due to some good history with prior products from the manufacturer. https://smile.amazon.com/gp/product/B075FPQ2YQ/
2. Previously used this four-pack.  This was so there was a master power switch to all motors, then individuals for each motor.  Can simplify down to just the one, but the multiples had helped with some debugging in the past (can always just unplug the barrel jack instead). https://smile.amazon.com/gp/product/B082Y37QRV/
3. Great.
4. Great.

Closed 2021-08-03.

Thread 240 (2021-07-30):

Inconsistent drill hole sizes in Mimic Shield

cactus314, 2021-07-30:
In the latest batch of Mimic Shields I received (July 2021), the thru-holes for P1 (pins 8 - GND) are larger in diameter than the other holes.  They'll still work, just a sloppier fit.  Was this intentional?
We should also mention in the documentation that J6 (I2C connection) is not meant to have anything soldered to it (or at least I assume not), and also that this isn't a full shield - i.e., not all of the sockets in the motor shield below will have a pin inserted.
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

ISS-Mimic, 2021-08-04:
oh weird yeah maybe replaced the component and I didn't realize it had different hole sizes. I'll fix that, glad it still works. good note about J6, it's just a test port that I don't think we've even used haha

Closed 2021-08-08.

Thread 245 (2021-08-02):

Need to add shaft coupler set screws used on SAWs to BOM

cactus314, 2021-08-02:
What size thread and what length is used to replace the small setscrews that come with the couplers?

ISS-Mimic, 2021-08-04:
Is this just for if the screws get lost? The set screws should come with the couplers right?

cactus314, 2021-08-04:
I thought @juggler2000 told me that y'all replaced the originals with longer set screws for... reasons.  Maybe I misunderstood.

juggler2000, 2021-08-04:
yes, we use longer screws. The thought was to help retain the coupler within the solar array wing. Might be overkill. This is the rediculous screw set we bought, but I don't recall the size screw we used.

Hilitchi 260pcs M3/4/5/6/8 Allen Head Socket Hex Grub Screw Set Assortment Kit with Plastic Box 12.9 Class Black Alloy Steel https://smile.amazon.com/dp/B014OMFU1I/ref=cm_sw_r_apan_glt_fabc_7WH2CD7T6AQXY4PDRB6X?_encoding=UTF8&psc=1

SpaceTowel, 2021-08-04:
Patrick to remove set screw from Mimic and do measurement, and update BOM.

cactus314, 2021-08-07:
The set screws that come with the couplers are M3 x 3mm.  The set screw I removed from the model was an M3 x 6mm.
Recommend BOM item from McMaster: [Stainless Steel Flat-Tip Set Screw](https://www.mcmaster.com/92605A100/) rather than an assortment set from Amazon.  I'll update the BOM with these.

Closed 2021-08-07.

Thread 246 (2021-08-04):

Spec out 2-ft HDMI cables instead of 3-ft cables

cactus314, 2021-08-04:
The cables listed in the [HDMI Cable BOM](https://github.com/ISS-Mimic/Mimic/wiki/Build-Instruction%3A-Bill-of-Materials#hdmi-cables) are for a 3-pack of 3-ft cables (qty 2).  I didn't pay attention and ordered them, but they're really too long.
Suggest changing to [Cable Builders Short HDMI Cable 2-ft [2-Pack]](https://www.amazon.com/Cable-Builders-2-Pack-Ethernet-18GBps/dp/B07LFN7CX6), qty 3.  It's a couple of dollars more overall but removes having HDMI cable looping out from the frame.

I plan to return the ones I ordered and replace them with 2-ft cables.

ISS-Mimic, 2021-08-04:
Yeah good idea, dang I thought 3 ft was the good size but I remember going through this exact same thing

ISS-Mimic, 2021-08-04:
also sorry, I've been on vacation and then on work travel now so haven't been able to work on mimic stuff in a bit

Closed 2021-08-05.

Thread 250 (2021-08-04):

New part order with new silk screen update from ticket 241 + 242

SpaceTowel, 2021-08-04:

cactus314, 2021-08-05:
@juggler2000 - Just to be clear.  You want me to use HDMI breakout boards and IEA Boards with the updated silkscreens on the build I'm currently working on?  That'll slow me down a little, but that's okay.  We have time.
@streadgold - What's the timeframe for updating the gerber files for those two boards?  Let me know when they're ready to go and I'll get the new boards on order.  I might have to go through the process of verifying the orientation of the screw terminals with JLCPCB again.

streadgold, 2021-08-05:
Should be able to do that tomorrow if I remember

cactus314, 2021-08-05:
> Should be able to do that tomorrow if I remember

Do you need dimensions for the offsets/terminal blocks?

streadgold, 2021-08-05:
Nope I already have the dimensions

juggler2000, 2021-08-05:
Yes, I was thinking of using the revised boards in your design, for photos and later debugging purposes. If that's a significant slowdown for you, then just proceed with what you have. Sounds like Sam is on it, though.

cactus314, 2021-08-09:
@streadgold & @juggler2000 - On the HDMI breakouts, there's an inventory shortage of the header pins @ JLCPCB (presumably the ones for the servos).  I'm tempted to order anyway and solder in those pins myself just to keep things moving.  Thoughts?
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

cactus314, 2021-08-09:
Or is that not how it works and they'll hold production until the parts become available?

cactus314, 2021-08-09:
Now that I'm exploring the tool, I see you can change parts.  Is this an acceptable replacement?
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

cactus314, 2021-08-09:
Or basically any straight three-pin header?
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

streadgold, 2021-08-09:
Yes any 2.54mm pitch 3 pin header should work, that looks fine to me.

To answer your first question I'm not sure if they would hold product. I think if you just uncheck the part it would probably go through and just ignore that part

cactus314, 2021-08-09:
Had a minimum order of 50pcs for the 3-pin headers... not sure why, but fortunately they're super cheap.

Closed 2021-08-09.

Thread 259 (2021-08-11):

Switching neopixle control board to metro mini

SpaceTowel, 2021-08-11:

cactus314, 2021-08-12:
This is really a repeat of Issue #187 : "Replace LED-driving Ard Mega with Nano or similar"

cactus314, 2021-08-14:
_Sooooo_,
I've been playing with the Neopixels on the STEM Mimic.  (They don't all work, but that's another ticket.)
The Adafruit Metro Mini (and apparently the regular Metro 328) uses a SiLabs CP2104 hardware USB to Serial converter for USB connectivity (see [technical details](https://www.adafruit.com/product/2590#technical-details)).  They claim that this is well supported, but I can't get the Mini or a Metro 328 to respond to serial commands from the RPi (i.e., the onboard Rx LED doesn't flash and the Neopixels don't respond to commands from the RPi).  If I try an old Sparkfun RedBoard or use an Adafruit Metro M0 Express (the ones used for the motors), they receive the serial data just fine.  Interestingly, the Metro Mini and Metro 328 do show up as added Arduinos on the controller count on the Mimic GUI, they just don't receive data.

**Options**: I can try an Arduino Nano clone (needs to come with the pins not soldered so I can put them in upside down), but they usually require a USB-Mini rather than the USB-Micro that the Metros use - it would be nice for all the cables to be the same,  Alternatively we could go with a full-sized Arduino Uno clone that has a friendly USB converter.  Perhaps the best thing is to just add a 4th Metro M0 Express.  It makes the programming environment more consistent for the user, simplifies the BOM, and doesn't add that much cost - plus we know they work,
What say ye, @streadgold & @juggler2000?

juggler2000, 2021-08-14:
Interesting. I'm fine with a fourth Metro M0 Express. Thanks for all the work!

streadgold, 2021-08-14:
I'd be curious about getting a nano to work - just from a form factor perspective. If it doesn't work right off the bat though wouldn't put too much effort into it

streadgold, 2021-08-14:
Or like a trinket or something micro USB based, agreed that mini USB would be an obnoxious requirement

cactus314, 2021-08-15:
@streadgold - If I were smarter, I might be able to get the RPi to talk to the CP2104 ([reference here](https://www.raspberrypi.org/forums/viewtopic.php?t=255114)) on the Mini, but that'll take me some time to work through.  I'll order a Nano clone just to see if it works.  I didn't think the Trinkets had the USB/serial com capability required.
Most folks probably have extra USB-Micro cables scattered about, but it would be a shame to have to add them to the BOM for completeness.

streadgold, 2021-08-15:
@cactus314 good point, the standard trinket does not have a serial port but the trinket M0 does and I believe the pro micro does as well

cactus314, 2021-08-17:
@streadgold - I think I can make the Trinket M0 work wrt taking commands from the RPi, but it only has a single ground pin.  I measured the current in the ground wire between the Mimic Shield and the Neopixel controller (the Metro M0 I'm using right now), and see a draw of at least 120mA, so I don't think I can cheat and use one of the digital pins on the Trinket M0 as a GND to sink that much current.  We'd have to have the users make their own jumper to run two GNDs (port and starboard) from the single pin.  Not sure we want to ask folks to make their own jumpers.
I got in some Nano clones too, but I haven't tried them yet.  I suspect they'll work, but I was hoping for the Trinket M0.
I'm not sure what you're referring to with the "Pro Micro".  There's a "[Pro Trinket](https://www.adafruit.com/product/2010)", but it doesn't have a Serial-USB converter.

cactus314, 2021-08-17:
I suppose I could set Pin 4 low in the code and solder bridge it to GND on the backside as a cheat.  I don't know what bad things might happen that way.  It _should_ work okay.
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

streadgold, 2021-08-17:
Ah yeah didnt realize it only had the one ground pin. Might be more trouble than it's worth.

This is a pro micro https://www.sparkfun.com/products/12640 (or the sparkfun version, there are lots of cheap clones out there).

cactus314, 2021-08-17:
Metro Mini won't work due to an insufficient number of ground pins.  Closing out this Issue.  Issue #187 remains open to work on changing to a smaller device.  (Will try a Pro Micro next.)

Closed 2021-08-17.

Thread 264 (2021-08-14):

STEM Mimic touchscreen not turning on

cactus314, 2021-08-14:
The RPi is on (I can see the light), but the display is not coming on.  I suspect a loose connection in the display ribbon cable, but nothing was changed/moved to cause a failure.  Is this a recurring problem?

cactus314, 2021-08-14:
The screen would not come on with the USB hub attached.  Unplugged the HUB, rebooted, the screen came on, plugged in HUB and all is good.  Not sure what's up, but closing this ticket unless it happens again.

streadgold, 2021-08-14:
Was the USB hub power on? I've seen the Pi lock up from too much USB current draw before. Haven't quite experienced what you mentioned before though

cactus314, 2021-08-15:
@streadgold - I don't recall.  But I do know that I occasionally get "low power" notifications on the STEM Pi, which seems strange since the hub is powered.

Closed 2021-08-14.

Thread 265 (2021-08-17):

Updates needed for BOM

cactus314, 2021-08-17:
This is @cactus314 's BOM to-do list.  Add to as needed:

- [x] Change assorted jumper wires length from 30cm to 20cm variety
- [x] Add bamboo skewers for pinning some of the module model halves together
- [x] Add cyanoacrylate glue
- [ ] Add marked N/S magnet: https://www.kjmagnetics.com/proddetail.asp?prod=D84PC-RB&cat=163
- [x] Change Metro Mini to something else (possibly [Trinket M0](https://www.adafruit.com/product/3500)) for control of Neopixels after additional testing confirms suitability

cactus314, 2021-09-01:
Marked magnets from K&J have arrived.  Need to test using them in my assembly method before committing them to the BOM, or modify my assembly method to simply use them for marking magnets.

Closed 2023-08-24.

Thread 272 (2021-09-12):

Motor mount screws may need a different supplier

streadgold, 2021-09-12:
Was looking at the BOM and there is only "see all buying options" for the motor mount screws. Seems like they are not widely available. 8mm option was prime though, but cutting the screws seems like a last resort

Even if choosing the one buying option available we would need to update the prices

cactus314, 2021-09-12:
Could go with McMaster as the supplier (we already have them for other items).
https://www.mcmaster.com/m16x6mm/flat-head-screws/system-of-measurement~metric/thread-size~m1-6/length~6-mm/

Digisembler, 2021-09-15:
Thanks for the suggestion @cactus314!  BOM updated. issue closed.

Closed 2021-09-15.

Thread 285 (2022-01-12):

Entire Truss tilt backward - rods not long enough + flip inboard truss mount

SpaceTowel, 2022-01-12:

Digisembler, 2022-02-16:
Pulled #10 × 1.5" bolts, replaced with bamboo skewer piece, wrapped w clear tape on the ends to be tight in the hole in the truss. length cut to hold truss level.

Closed 2022-02-16.

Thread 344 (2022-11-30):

Ensure Build Guide includes Motor Shield config

juggler2000, 2022-11-30:
Ensure Build Guide includes the following mods to motor shields:
1) Removed jumper header (typically yellow) that's on Vin power.  This allows for use of the external power terminal screws.
2) Cut the 5v logic trace on top of the board.  Use a soldering iron to bridge the 3v logic jumper.  Failing to do so will likely result in burning out pins on the Arduino Metro, which uses 3v logic.

juggler2000, 2024-01-10:
Will be part of Edu activities this Spring, so closing here.

Closed 2024-01-10.

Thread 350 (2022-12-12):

Increase diameter of motor mount screw holes.

juggler2000, 2022-12-12:
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

Digisembler, 2022-12-13:
I've found that if one uses a drill bit, this is immensely helpful to enlarge a hole that might be slightly undersized from printing on a potentially less than superbly tuned 3d printer/slicer combo. :)  I suggest removing the shown screw, measure the diameter of the screw, and use that size drill bit on both holes (possibly on all holes for these motors), then reinsert the motor and tighten down with the screws.  While not in the BOM, a set of wire gauge drill bits is super helpful, but likely a standard or jewelers set from harbor freight or amazon, etc. would be close enough to widen the holes.  Go slowly, as if you spin a drill fast into 3d printed parts, you create a lot of heat that could deform the part more than you want.  I also do believe that these holes are countersunk, so once widening the holes, using a countersink bit to clean up the countersink may also be helpful.

juggler2000, 2022-12-13:
Let's keep the issues open until solutions are in the build. guide and reflected in the BOM.

juggler2000, 2024-01-24:
@SpaceTowel , did you have this issue with the recent build?  @Digisembler thinks it may have been a printer settings issue (if that's the case, need to add words to check size/drill out or define print parameters).

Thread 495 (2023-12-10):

shave 1.5 mm off base of iROSA to prevent interference with motor encoder

SpaceTowel, 2023-12-10:

Closed 2023-12-10.

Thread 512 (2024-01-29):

Update Mimic Frame CAD Model

streadgold, 2024-01-29:
Hey @Digisembler, can you update the aluminum frame model? The one we have in the integrated mimic model is definitely outdated

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

The 6x side legs are definitely the wrong length, and the L-brackets are the small version when at least some of them should be the large version.

This is crucial since its the only reference for folks building their own

streadgold, 2024-01-31:
https://github.com/ISS-Mimic/Mimic/blob/main/Wiki/Mimic%20One%20Frame%20Updated.pptx

Digisembler, 2024-01-31:
Model can get updated - the powerpoint of the frame build is in the wiki under Mimic One Frame Updated.pptx

Digisembler, 2024-02-03:
So there are some issues with the tool i'm using for this - i cannot add the T plates and as far as i can tell, there's only the small 90 degree brackets.  We'll just have to point out which are which, or cad up those brackets from outside the tool.  Updated dimensions as best possible to the link above, realizing that everyone's specific build may have to adjust slightly for their build.  Step file included here to check out and receive comments back.
[UpdatedFrame240203.zip](https://github.com/ISS-Mimic/Mimic/files/14154288/UpdatedFrame240203.zip)

Closed 2024-02-14.

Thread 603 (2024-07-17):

Bill of Materials not formatted correctly

TheRealFakeAdmin, 2024-07-17:
## Description
The [Bill of Materials](https://github.com/ISS-Mimic/Mimic/wiki/Build-Instruction%3A-Bill-of-Materials) wiki page formatting is missing the bullet points/new-lines under the sections [Required Tools](https://github.com/ISS-Mimic/Mimic/wiki/Build-Instruction%3A-Bill-of-Materials#required-tools) & [Useful Tools](https://github.com/ISS-Mimic/Mimic/wiki/Build-Instruction%3A-Bill-of-Materials#useful-tools).

## Current
```
### Required Tools
3D Printer
Small Phillips Head Screw Driver
Soldering Iron (if assembling boards)

### Useful Tools
Deburring Tool for cleaning up 3d prints
Drill bits for opening up plastic holes
Multimeter for debugging
Paint Pens / Airbrush for aesthetics
Caffeine
```

## Expected
```
### Required Tools
- 3D Printer
- Small Phillips Head Screw Driver
- Soldering Iron (if assembling boards)

### Useful Tools
- Deburring Tool for cleaning up 3d prints
- Drill bits for opening up plastic holes
- Multimeter for debugging
- Paint Pens / Airbrush for aesthetics
- Caffeine
```

ISS-Mimic, 2024-07-19:
Done thanks for the copy pastability ;)

Closed 2024-07-19.

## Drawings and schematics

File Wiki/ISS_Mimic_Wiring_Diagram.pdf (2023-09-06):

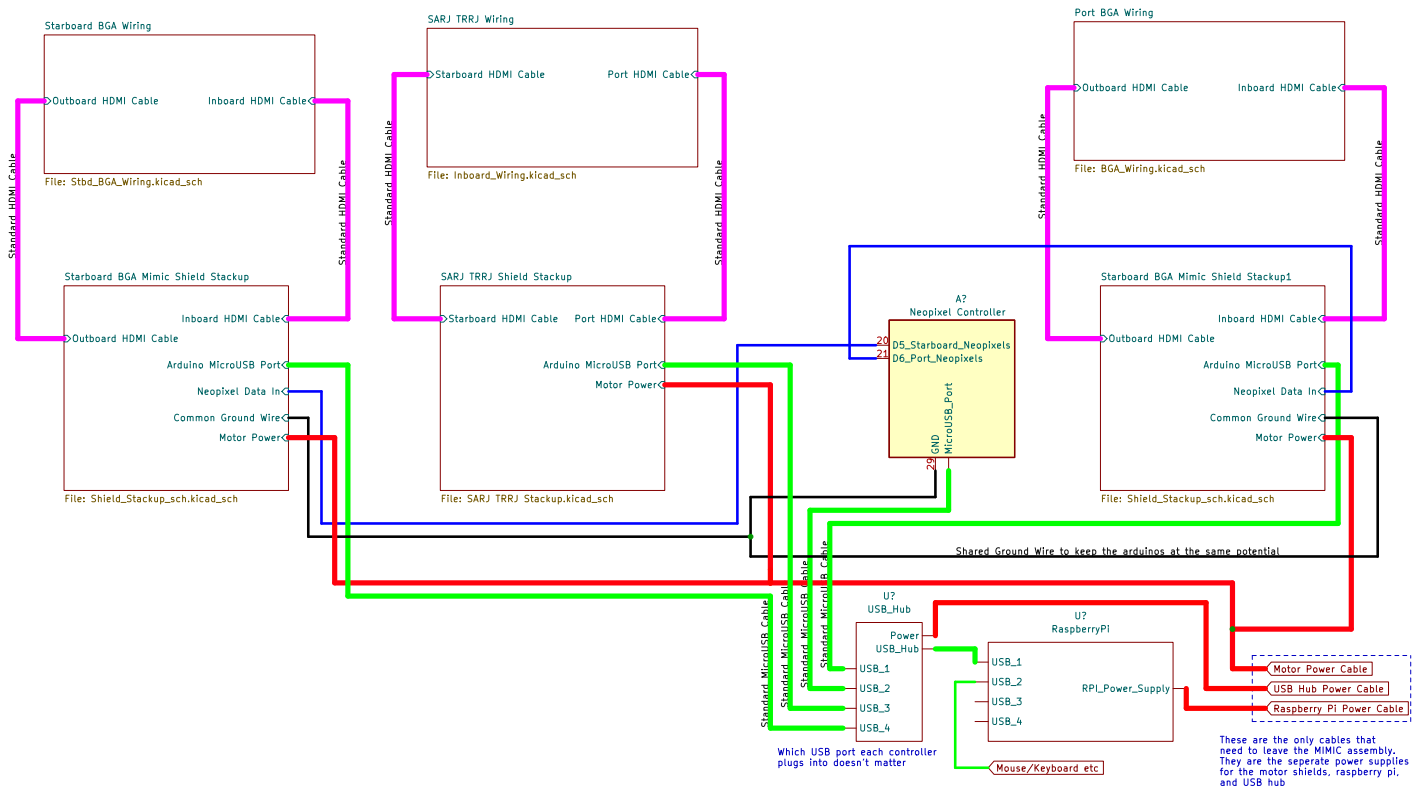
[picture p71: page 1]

Inboard HDMI Cable Arduino MicroUSB Port Starboard BGA Mimic Shield Stackup

Inboard HDMI Cable Arduino MicroUSB Port Starboard BGA Mimic Shield Stackup1

Neopixel Data In Outboard HDMI Cable

Shared Ground Wire to keep the arduinos at the same potential

These are the only cables that
need to leave the MIMIC assembly.
They are the seperate power supplies
for the motor shields, raspberry pi, and USB hub

Which USB port each controller
plugs into doesn't matter

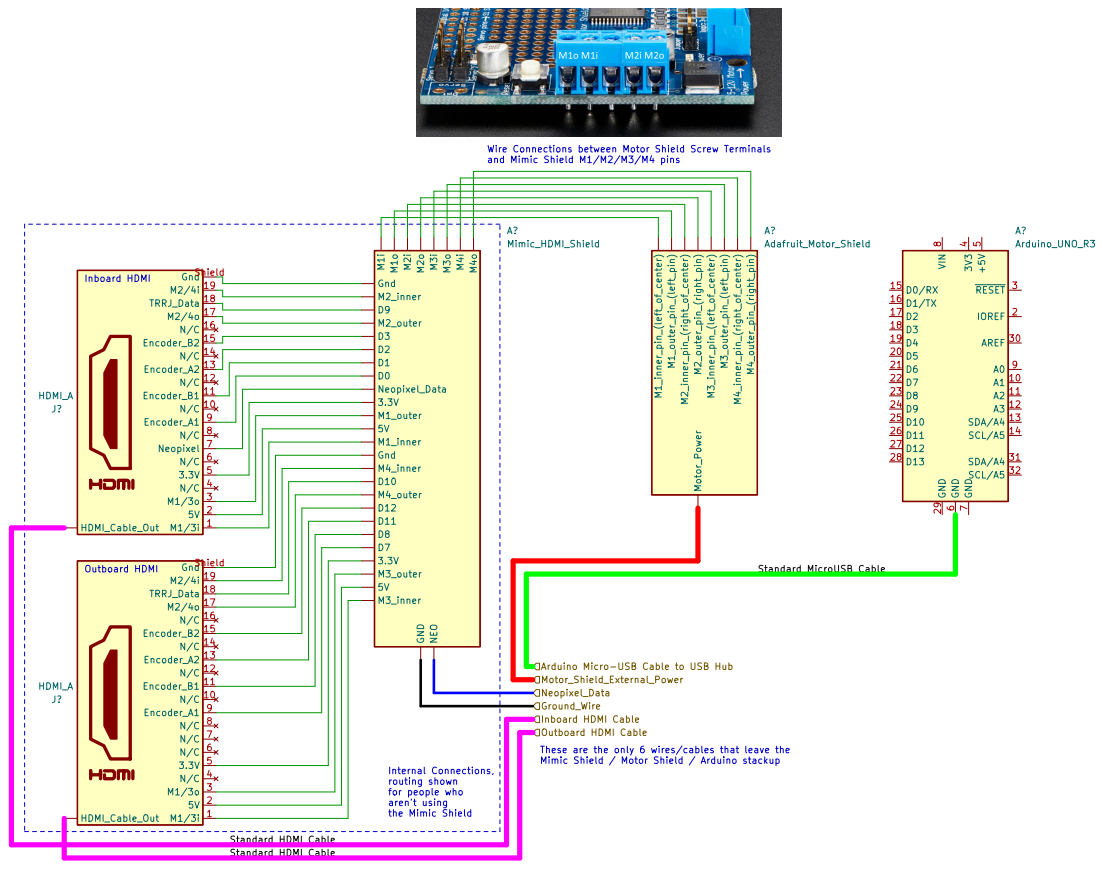
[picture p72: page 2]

Mimic Shield / Motor Shield / Arduino stackup

Internal Connections, routing shown

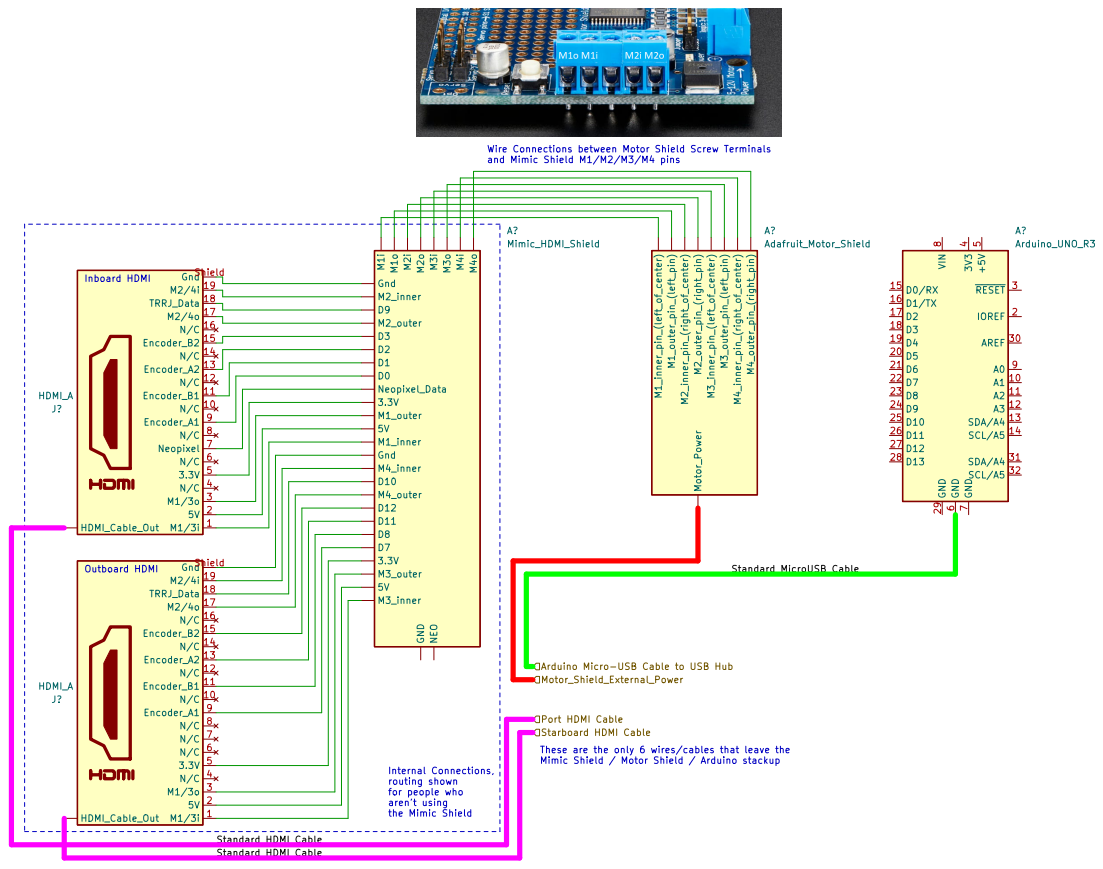
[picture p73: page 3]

8 A0 9A?Arduino_UNO_R3 Motor_Shield_External_Power Starboard HDMI Cable Port HDMI Cable Arduino Micro-USB Cable to USB Hub Standard HDMI Cable Standard HDMI Cable Standard MicroUSB Cable Wire Connections between Motor Shield Screw Terminals and Mimic Shield M1/M2/M3/M4 pins

Inboard HDMI Outboard HDMI

Mimic Shield / Motor Shield / Arduino stackup

Internal Connections, routing shown

Mimic Shield / Motor Shield / Arduino stackup

Internal Connections, routing shown

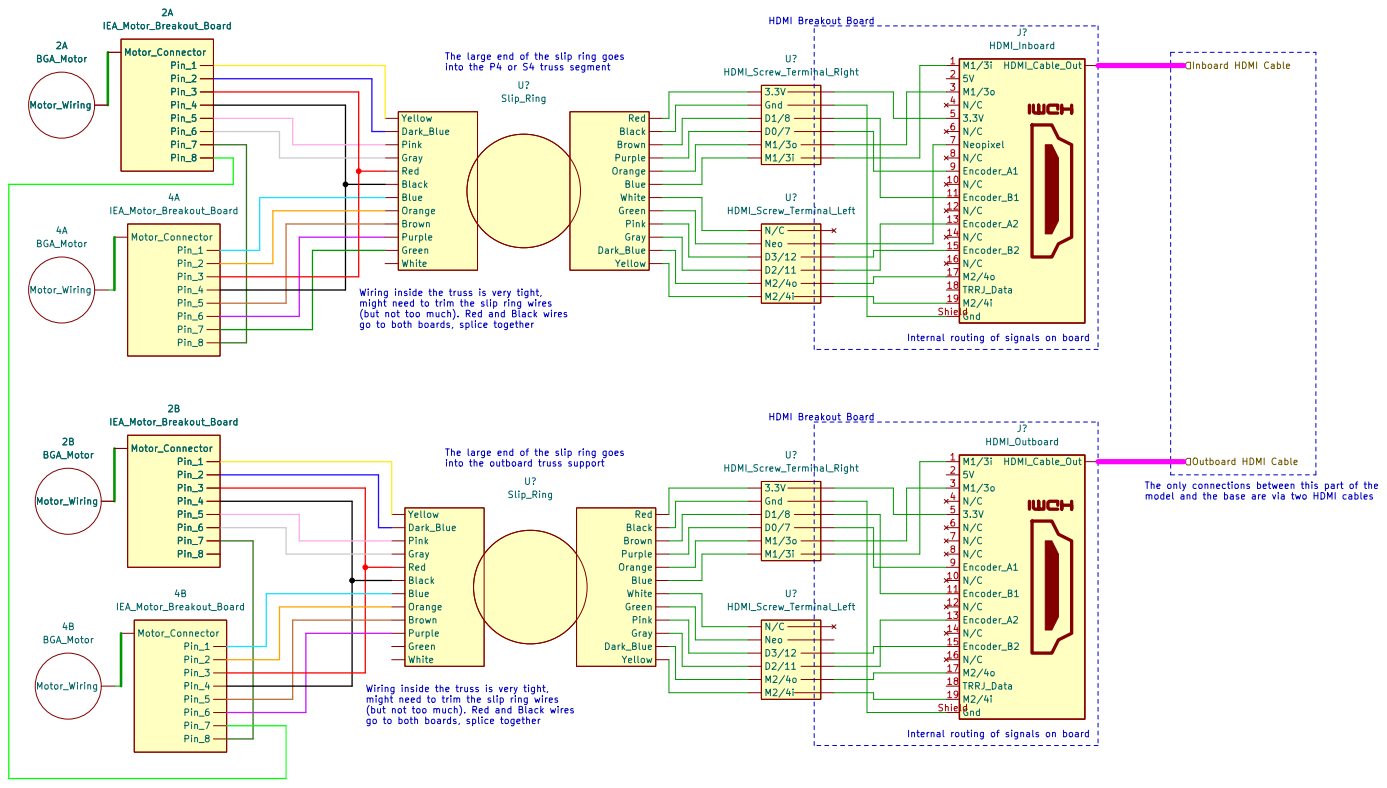
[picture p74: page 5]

HDMI Breakout Board Wiring inside the truss is very tight,

The large end of the slip ring goes
into the P4 or S4 truss segment

Inboard HDMI Cable Outboard HDMI Cable

might need to trim the slip ring wires
(but not too much). Red and Black wires

go to both boards, splice together 2B

Internal routing of signals on board HDMI Breakout Board

into the outboard truss support

The only connections between this part of the model and the base are via two HDMI cables

Wiring inside the truss is very tight,
go to both boards, splice together

Internal routing of signals on board

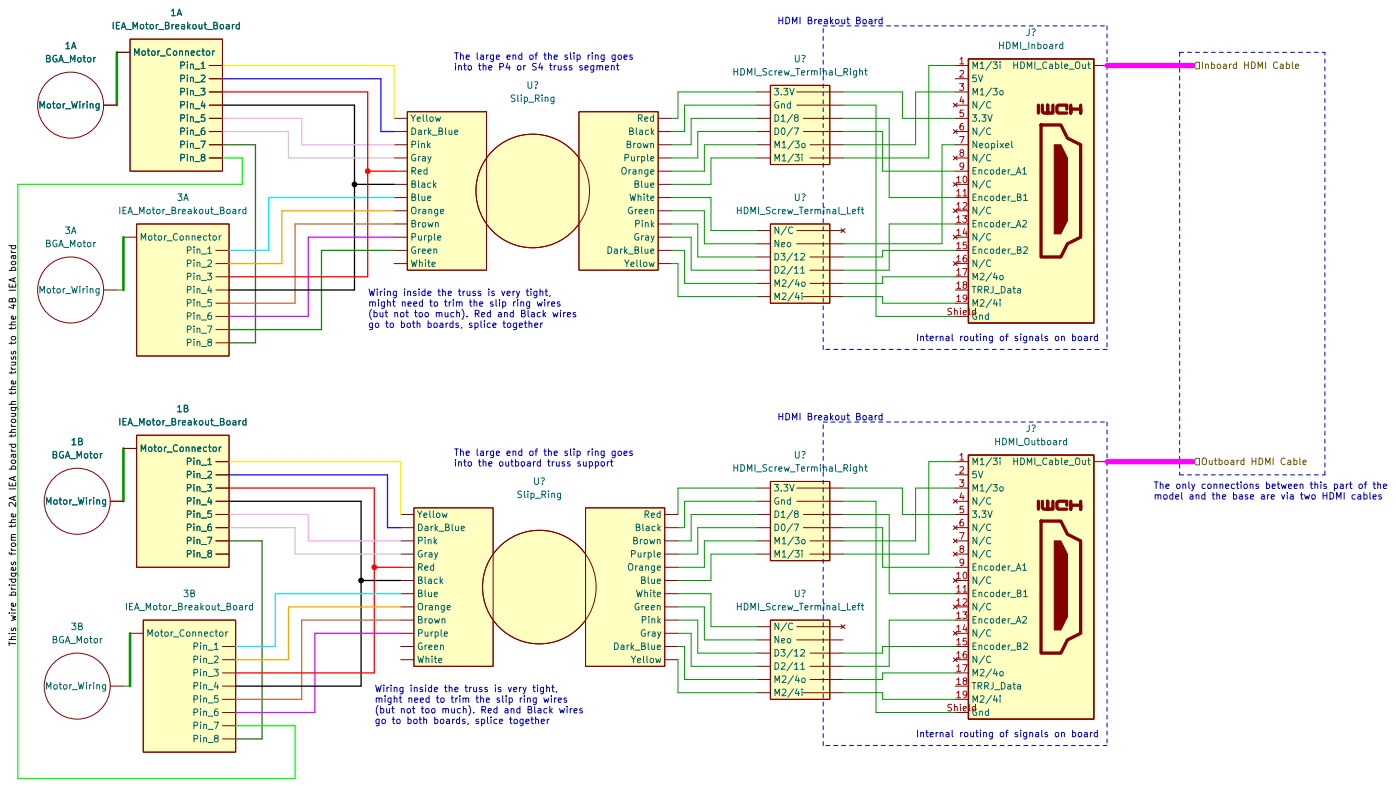
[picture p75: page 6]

The large end of the slip ring goes

Inboard HDMI Cable Outboard HDMI Cable This wire bridges from the 2A IEA board through the truss to the 4B IEA board

Wiring inside the truss is very tight,
might need to trim the slip ring wires
(but not too much). Red and Black wires

Internal routing of signals on board

into the outboard truss support

The only connections between this part of the model and the base are via two HDMI cables Wiring inside the truss is very tight,

go to both boards, splice together

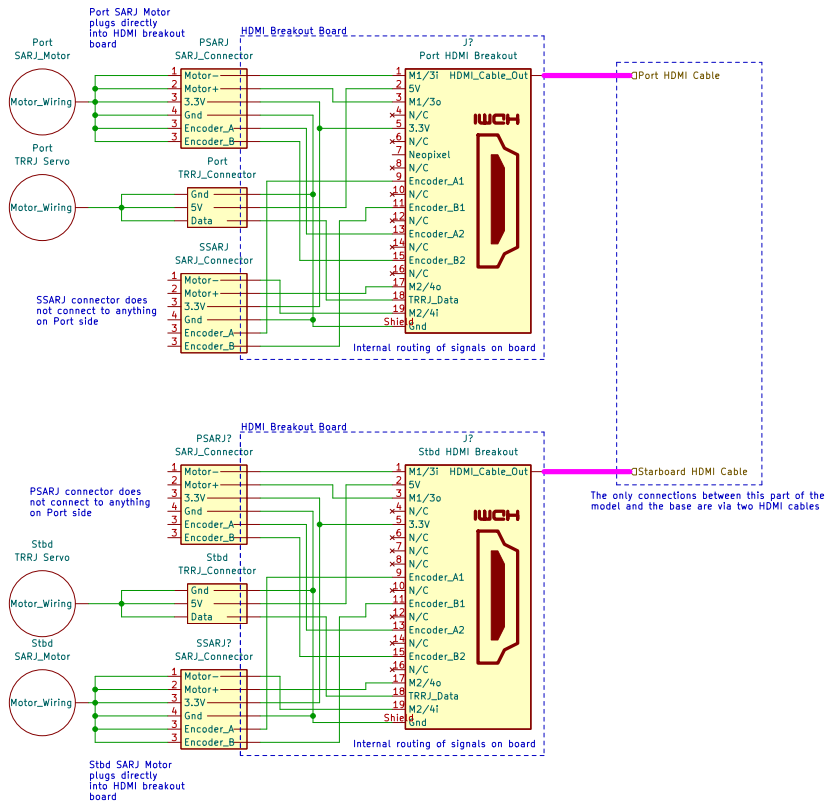
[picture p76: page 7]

Port SARJ Motor plugs directly

J? Port HDMI Breakout
on Port side Stbd SARJ Motor plugs directly
into HDMI breakout board PSARJ connector does not connect to anything

Internal routing of signals on board

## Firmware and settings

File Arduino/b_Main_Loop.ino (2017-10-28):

void loop() {

int  debug_mode=2;
  B4B = 100 + 90.0 ;//* sin(2.0 * 3.14159 * 0.001 * millis() / 1000.0);
  B2B = 100 + 90.0 ;//* sin(2.0 * 3.14159 * 0.01 * millis() / 1000.0);
  // commentedAug23  B2B=184.5+55.2*sin((1/60.)*2*3.14159*float(millis())/1000.0);
  //B4B=180;
  if (Serial3.available())
  {
    checkSerial();
  }
  /*

  // ========= Servo Stuff =============================
  for (i = 0; i < 255; i++) {
    servo1.write(map(i, 0, 255, 0, 180));
    // myMotor->setSpeed(i);
    // myStepper->step(1, FORWARD, DOUBLE);
    delay(3);
  }
  //delay(10);
  for (i = 255; i != 0; i--) {
    servo1.write(map(i, 0, 255, 0, 180));
    // myMotor->setSpeed(i);
    //myStepper->step(1, BACKWARD, DOUBLE);
    delay(3);
  }
  //delay(10);
  // ==================================================
*/
  // ============== Time measures ===================================================
  LoopStartMillis = millis();
  delta_t_millis = max(LoopStartMillis - previousMillis, 1); // ensure always equal to at least one, for later inversion
  inverse_delta_t_millis = (float) delta_t_millis;
  millisChPt1 = millis() - LoopStartMillis;
  // ================================================================================

  //ManualSpeed   Count_B4A = myEnc4A.read(); // Feb08
  //ManualSpeed   Count_B2A = myEnc2A.read(); // Feb08
  //ManualSpeed   Count_B4B = myEnc4B.read(); // Feb08
  Count_B2B = myEnc2B.read(); // Feb08
  Count_B4B = myEnc4B.read();
  Count_B2A = myEnc2A.read();
  Count_B4A = myEnc4A.read();
  //   Serial.println(currentPosition); //shows you the current position in the serial monitor  // Feb08

  // ============== BGA 2A ==========================================================

  // 150 motor shaft rotations / gearbox output shaft rotation * 12 encoder counts / motor rotation  /(360 deg per /output rotation) = 150*12/360 = 5 encoder counts per output shaft degree
  Pos_B2A = float(Count_B2A) / 5;

  PosErr_B2A = B2A - Pos_B2A; // Compute Pos_B2Aition Error
  dPosErr_B2A = PosErr_B2A - PosErr_old_B2A;

  if (abs(PosErr_B2A) < 0.1) {
    PosErr_B2A = 0;
    dPosErr_B2A = 0;
    PosErr_old_B2A = 0;
    IntOld_B2A = 0;
    //Serial.println("Small2A Err");
  }

  dErrDt_B2A = dPosErr_B2A * inverse_delta_t_millis * 0.001; // For Derivative
  IntNow_B2A = IntOld_B2A + PosErr_B2A * inverse_delta_t_millis * 0.001; // For Integrator
  IntOld_B2A = IntNow_B2A;

  // Integrator reset when error sign changes
  if (PosErr_old_B2A * PosErr_B2A <= 0) { // sign on error has changed or is zero
    IntNow_B2A = 0;
    IntOld_B2A = 0;
  }
  PosErr_old_B2A = PosErr_B2A; // For use on the next iteration

  // Calculate motor speed setpoint based on PID constants and computed params for this iteration.
  tmpSpeed_B2A = Kp_B2A * PosErr_B2A + Kd_B2A * (dErrDt_B2A) + Ki_B2A * IntNow_B2A;
  // Deadband seems to be about 40 (for 5V input to motor board);
  CmdSpeed_B2A = abs(tmpSpeed_B2A);
  if ((CmdSpeed_B2A < 40) && (CmdSpeed_B2A > 5)) { // We want a dead space at 5 counts, but want it to move for larger vals.
    CmdSpeed_B2A = 40;
  }

 CmdSpeed_B2A = max(min(CmdSpeed_B2A, 250), 0); // At least 10, at most 250.  Update as needed per motor.

  // Set motor speed
  if (tmpSpeed_B2A > 0) {
    myMotorB2A->run(FORWARD); // This command is necessary for the AdaFruit boards, requiring conditionals (rather than signed speeds taking care of direction).
  }
  else {
    myMotorB2A->run(BACKWARD);
  }
  myMotorB2A->setSpeed(CmdSpeed_B2A);// + 20);
  //=====================================================================================

  // ============== BGA 2B ==========================================================

  // 150 motor shaft rotations / gearbox output shaft rotation * 12 encoder counts / motor rotation  /(360 deg per /output rotation) = 150*12/360 = 5 encoder counts per output shaft degree
  Pos_B2B = float(Count_B2B) / 5;

  PosErr_B2B = B2B - Pos_B2B; // Compute Pos_B2Bition Error
  dPosErr_B2B = PosErr_B2B - PosErr_old_B2B;

  if (abs(PosErr_B2B) < 0.1) {
    PosErr_B2B = 0;
    dPosErr_B2B = 0;
    PosErr_old_B2B = 0;
    IntOld_B2B = 0;
    //Serial.println("Small2B Err");
  }

  dErrDt_B2B = dPosErr_B2B * inverse_delta_t_millis * 0.001; // For Derivative
  IntNow_B2B = IntOld_B2B + PosErr_B2B * inverse_delta_t_millis * 0.001; // For Integrator
  IntOld_B2B = IntNow_B2B;

  // Integrator reset when error sign changes
  if (PosErr_old_B2B * PosErr_B2B <= 0) { // sign on error has changed or is zero
    IntNow_B2B = 0;
    IntOld_B2B = 0;
  }
  PosErr_old_B2B = PosErr_B2B; // For use on the next iteration

  // Calculate motor speed setpoint based on PID constants and computed params for this iteration.
  tmpSpeed_B2B = Kp_B2B * PosErr_B2B + Kd_B2B * (dErrDt_B2B) + Ki_B2B * IntNow_B2B;
  // Deadband seems to be about 40 (for 5V input to motor board);
  CmdSpeed_B2B = abs(tmpSpeed_B2B);
  if ((CmdSpeed_B2B < 40) && (CmdSpeed_B2B > 5)) { // We want a dead space at 5 counts, but want it to move for larger vals.
    CmdSpeed_B2B = 40;
  }

  CmdSpeed_B2B = max(min(CmdSpeed_B2B, 250), 0); // At least 10, at most 250.  Update as needed per motor.

  // Set motor speed
  if (tmpSpeed_B2B > 0) {
    myMotorB2B->run(FORWARD); // This command is necessary for the AdaFruit boards, requiring conditionals (rather than signed speeds taking care of direction).
  }
  else {
    myMotorB2B->run(BACKWARD);
  }
  myMotorB2B->setSpeed(CmdSpeed_B2B);// + 20);
  //=====================================================================================

  // ============== BGA 4A ==========================================================

  // 150 motor shaft rotations / gearbox output shaft rotation * 12 encoder counts / motor rotation  /(360 deg per /output rotation) = 150*12/360 = 5 encoder counts per output shaft degree
  Pos_B4A = float(Count_B4A) / 5;

  PosErr_B4A = B4A - Pos_B4A; // Compute Pos_B4Aition Error
  dPosErr_B4A = PosErr_B4A - PosErr_old_B4A;

  if (abs(PosErr_B4A) < 0.1) {
    PosErr_B4A = 0;
    dPosErr_B4A = 0;
    PosErr_old_B4A = 0;
    IntOld_B4A = 0;
    //Serial.println("Small4A Err");
  }

  dErrDt_B4A = dPosErr_B4A * inverse_delta_t_millis * 0.001; // For Derivative
  IntNow_B4A = IntOld_B4A + PosErr_B4A * inverse_delta_t_millis * 0.001; // For Integrator
  IntOld_B4A = IntNow_B4A;

  // Integrator reset when error sign changes
  if (PosErr_old_B4A * PosErr_B4A <= 0) { // sign on error has changed or is zero
    IntNow_B4A = 0;
    IntOld_B4A = 0;
  }
  PosErr_old_B4A = PosErr_B4A; // For use on the next iteration

  // Calculate motor speed setpoint based on PID constants and computed params for this iteration.
  tmpSpeed_B4A = Kp_B4A * PosErr_B4A + Kd_B4A * (dErrDt_B4A) + Ki_B4A * IntNow_B4A;
  // Deadband seems to be about 40 (for 5V input to motor board);
  CmdSpeed_B4A = abs(tmpSpeed_B4A);
  if ((CmdSpeed_B4A < 40) && (CmdSpeed_B4A > 5)) { // We want a dead space at 5 counts, but want it to move for larger vals.
    CmdSpeed_B4A = 40;
  }

  CmdSpeed_B4A = max(min(CmdSpeed_B4A, 250), 0); // At least 10, at most 250.  Update as needed per motor.

  // Set motor speed
  if (tmpSpeed_B4A > 0) {
    myMotorB4A->run(FORWARD); // This command is necessary for the AdaFruit boards, requiring conditionals (rather than signed speeds taking care of direction).
  }
  else {
    myMotorB4A->run(BACKWARD);
  }
  myMotorB4A->setSpeed(CmdSpeed_B4A);// + 20);
  //=====================================================================================


  // ============== BGA 4B ==========================================================

  // 150 motor shaft rotations / gearbox output shaft rotation * 12 encoder counts / motor rotation  /(360 deg per /output rotation) = 150*12/360 = 5 encoder counts per output shaft degree
  Pos_B4B = float(Count_B4B) / 5;

  PosErr_B4B = B4B - Pos_B4B; // Compute Pos_B4Bition Error
  dPosErr_B4B = PosErr_B4B - PosErr_old_B4B;

  if (abs(PosErr_B4B) < 0.1) {
    PosErr_B4B = 0;
    dPosErr_B4B = 0;
    PosErr_old_B4B = 0;
    IntOld_B4B = 0;
    //Serial.println("Small4B Err");
  }

  dErrDt_B4B = dPosErr_B4B * inverse_delta_t_millis * 0.001; // For Derivative
  IntNow_B4B = IntOld_B4B + PosErr_B4B * inverse_delta_t_millis * 0.001; // For Integrator
  IntOld_B4B = IntNow_B4B;

  // Integrator reset when error sign changes
  if (PosErr_old_B4B * PosErr_B4B <= 0) { // sign on error has changed or is zero
    IntNow_B4B = 0;
    IntOld_B4B = 0;
  }
  PosErr_old_B4B = PosErr_B4B; // For use on the next iteration

  // Calculate motor speed setpoint based on PID constants and computed params for this iteration.
  tmpSpeed_B4B = Kp_B4B * PosErr_B4B + Kd_B4B * (dErrDt_B4B) + Ki_B4B * IntNow_B4B;
  // Deadband seems to be about 40 (for 5V input to motor board);
  CmdSpeed_B4B = abs(tmpSpeed_B4B);
  if ((CmdSpeed_B4B < 40) && (CmdSpeed_B4B > 5)) { // We want a dead space at 5 counts, but want it to move for larger vals.
    CmdSpeed_B4B = 40;
  }

  CmdSpeed_B4B = max(min(CmdSpeed_B4B, 250), 0); // At least 0, at most 250.  Update as needed per motor.

  // Set motor speed
  if (tmpSpeed_B4B > 0) {
    myMotorB4B->run(FORWARD); // This command is necessary for the AdaFruit boards, requiring conditionals (rather than signed speeds taking care of direction).
  }
  else {
    myMotorB4B->run(BACKWARD);
  }
  myMotorB4B->setSpeed(CmdSpeed_B4B);// + 20);
  //=====================================================================================

  //  // ============== PSARJ    ============================================================
  //  Pos_PSARJ = float(Count_PSARJ) / 2.5; // / 25; // 150:1 gear ratio, 6 encoder counts per motor shaft rotation 150/6=25;
  //
  //  PosErr_PSARJ = PSARJ - Pos_PSARJ; // Compute Pos_PSARJition Error
  //  dPosErr_PSARJ = PosErr_PSARJ - PosErr_old_PSARJ;
  //  dErrDt_PSARJ = dPosErr_PSARJ * inverse_delta_t_millis * 0.001; // For Derivative
  //  IntNow_PSARJ = IntOld_PSARJ + PosErr_PSARJ * inverse_delta_t_millis * 0.001; // For Integrator
  //  IntOld_PSARJ = IntNow_PSARJ;
  //  PosErr_old_PSARJ = PosErr_PSARJ; // For use on the next iteration
  //  // Integrator reset when error sign changes
  //  if (PosErr_old_PSARJ * PosErr_PSARJ < 0) { // sign on error has changed
  //    IntNow_PSARJ = 0;
  //    IntOld_PSARJ = 0;
  //  }
  //
  //  // Calculate motor speed setpoint based on PID constants and computed params for this iteration.
  //  tmpSpeed_PSARJ = Kp_PSARJ * PosErr_PSARJ + Kd_PSARJ * (dErrDt_PSARJ) + Ki_PSARJ * IntNow_PSARJ;
  //  CmdSpeed_PSARJ = map(abs(tmpSpeed_PSARJ), 2, 250, 2, 250); // Deadband seems to be about 40 (for 5V input to motor board);
  //  CmdSpeed_PSARJ = max(min(CmdSpeed_PSARJ, 150), 0); // At least 10, at most 250.  Update as needed per motor.
  //
  //  // Set motor speed
  //  if (tmpSpeed_PSARJ < 0) {
  //    myMotorPSARJ->run(FORWARD); // This command is necessary for the AdaFruit boards, requiring conditionals (rather than signed speeds taking care of direction).
  //  }
  //  else {
  //    myMotorPSARJ->run(BACKWARD);
  //  }
  //  myMotorPSARJ->setSpeed(CmdSpeed_PSARJ);// + 20);
  //  //====================================================================================

  millisChPt2 = millis() - LoopStartMillis;



  

  if (debug_mode==1) {
    response = "";
    response += "Ct2B:";
    response += Count_B2B;
    response += "|p2B:";
    response += Pos_B2B;
    response += "|2Bc:"; //commanded
    response += B2B;
    response += "|e2B:";
    response += PosErr_B2B;
    //    response += "|IntNw2B:";
    //    response += IntNow_B2B;
    //    response += "|dErrDt2B:";
    //    response += dErrDt_B2B;
    response += "|tp2B:";
    response += tmpSpeed_B2B;
    response += "|s2B:";
    response += CmdSpeed_B2B;

    response += "|Ct4B:";
    response += Count_B4B;
    response += "|p4B:";
    response += Pos_B4B;
    response += "|4Bcmd:";
    response += B4B;
    response += "|e4B:";
    response += PosErr_B4B;
    //    response += "|IntNw4B:";
    //    response += IntNow_B4B;
    //    response += "|dErrDt4B:";
    //    response += dErrDt_B4B;
    response += "|tp4B:";
    response += tmpSpeed_B4B;
    response += "|s4B:";
    response += CmdSpeed_B4B;

    response += "|Ct2A:";
    response += Count_B2A;
    response += "|p2A:";
    response += Pos_B2A;
    response += "|2Acmd:";
    response += B2A;
    response += "|e2A:";
    response += PosErr_B2A;
    //    response += "|IntNw2A:";
    //    response += IntNow_B2A;
    //    response += "|dErrDt2A:";
    //    response += dErrDt_B2A;
    response += "|tp2A:";
    response += tmpSpeed_B2A;
    response += "|s2A:";
    response += CmdSpeed_B2A;

    response += "|Ct4A:";
    response += Count_B4A;
    response += "|p4A:";
    response += Pos_B4A;
    response += "|4Acmd:";
    response += B4A;
    response += "|e4A:";
    response += PosErr_B4A;
    //    response += "|IntNw4A:";
    //    response += IntNow_B4A;
    //    response += "|dErrDt4A:";
    //    response += dErrDt_B4A;
    response += "|tp4A:";
    response += tmpSpeed_B4A;
    response += "|s4A:";
    response += CmdSpeed_B4A;
    millisChPt4 = millis() - LoopStartMillis;
    Serial.println(response);
    millisChPt5 = millis() - LoopStartMillis;
  }
  //
  //  response = "";
  //  response += Pos_B4B;
  //  Serial.println(response);


if (debug_mode==2){
Serial.print(B2B);
Serial.print(",");
Serial.print(Pos_B2B);
Serial.print(",");
Serial.print(CmdSpeed_B2B);
Serial.print(",");
Serial.print(tmpSpeed_B2B);
Serial.print("|,");
Serial.print(B4B);
Serial.print(",");
Serial.print(Pos_B4B);
Serial.print(",");
Serial.print(CmdSpeed_B4B);
Serial.print(",");
Serial.print(tmpSpeed_B4B);
millisChPt5 = millis() - LoopStartMillis;
Serial.print(", deltaT:");
Serial.println(millisChPt5);
}

if (debug_mode==3){
Serial.print(B2B);
Serial.print(",");
Serial.print(Pos_B2B);
Serial.print(",");
Serial.print(B4B);
Serial.print(",");
Serial.println(Pos_B4B);

}




  
  previousMillis = LoopStartMillis;

  millisChPt6 = millis() - LoopStartMillis;

  delay(3);
}

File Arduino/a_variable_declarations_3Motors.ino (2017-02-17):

// pins for the encoder inputs

String test;
unsigned long previousMillis = 0;
unsigned long LoopStartMillis = 0;
unsigned long  delta_t_millis = 1;
float inverse_delta_t_millis = 1;
uint8_t i;
unsigned long time;

// ======== B2B PID Vals=====================
//  PID Constants
float Kp_B2B = 20; // Proportional Gain of PID
float Ki_B2B = 0; // Integral Gain of PID
float Kd_B2B = 0; // Derivative Gain of PID

// B2B vars that change every iteration
int Count_B2B = 0;
float Pos_B2B=0;
float PosErr_B2B = 0;
float PosErr_B2B_old = 0;
float tmpSpeed_B2B = 0;
float dErrDt_B2B = 0;
float dPosErr_B2B=0;
float IntOld_B2B=0;
float IntNow_B2B=0;
int CmdSpeed_B2B=0;
// =============================================

// ======== B4B PID Vals=====================
//  PID Constants
float Kp_B4B = 20; // Proportional Gain of PID
float Ki_B4B = 0; // Integral Gain of PID
float Kd_B4B = 0; // Derivative Gain of PID

// B4B vars that change every iteration
int Count_B4B = 0;
float Pos_B4B=0;
float PosErr_B4B = 0;
float PosErr_B4B_old = 0;
float tmpSpeed_B4B = 0;
float dErrDt_B4B = 0;
float dPosErr_B4B=0;
float IntOld_B4B=0;
float IntNow_B4B=0;
int CmdSpeed_B4B=0;
// =============================================

// ======== B2A PID Vals=====================
//  PID Constants
float Kp_B2A = 20; // Proportional Gain of PID
float Ki_B2A = 0; // Integral Gain of PID
float Kd_B2A = 0; // Derivative Gain of PID

// B2A vars that change every iteration
int Count_B2A = 0;
float Pos_B2A=0;
float PosErr_B2A = 0;
float PosErr_B2A_old = 0;
float tmpSpeed_B2A = 0;
float dErrDt_B2A = 0;
float dPosErr_B2A=0;
float IntOld_B2A=0;
float IntNow_B2A=0;
int CmdSpeed_B2A=0;
// =============================================

// ======== B4A PID Vals=====================
//  PID Constants
float Kp_B4A = 20; // Proportional Gain of PID
float Ki_B4A = 0; // Integral Gain of PID
float Kd_B4A = 0; // Derivative Gain of PID

// B4A vars that change every iteration
int Count_B4A = 0;
float Pos_B4A=0;
float PosErr_B4A = 0;
float PosErr_B4A_old = 0;
float tmpSpeed_B4A = 0;
float dErrDt_B4A = 0;
float dPosErr_B4A=0;
float IntOld_B4A=0;
float IntNow_B4A=0;
int CmdSpeed_B4A=0;
// =============================================

//// ======== PSARJ PID Vals=====================
////  PID Constants
//float Kp_PSARJ = 50; // Proportional Gain of PID
//float Ki_PSARJ = 0; // Integral Gain of PID
//float Kd_PSARJ = 0; // Derivative Gain of PID
//
//// PSARJ vars that change every iteration
//int Count_PSARJ = 0;
//float Pos_PSARJ=0;
//float PosErr_PSARJ = 0;
//float PosErr_PSARJ_old = 0;
//float tmpSpeed_PSARJ = 0;
//float dErrDt_PSARJ = 0;
//float dPosErr_PSARJ=0;
//float IntOld_PSARJ=0;
//float IntNow_PSARJ=0;
//int CmdSpeed_PSARJ=0;
//// =============================================



// For debugging
int MyFlag;
String response="";
unsigned long millisChPt1 = 0;
unsigned long millisChPt2 = 0;
unsigned long millisChPt3 = 0;
unsigned long millisChPt4 = 0;
unsigned long millisChPt5 = 0;
unsigned long millisChPt6 = 0;
int LEDstatus=0; 


// ===== Initializations ==========
//PSARJ

boolean PSARJstartup = true;
double PSARJdiff = 0.00;
double oldPSARJstep = 0.00;
double oldPSARJangle = 0.00;
double oldPSARJ = 0.00;
double PSARJcheck = 0.00;
double PSARJstep = 0.00;


//SSARJ

boolean SSARJstartup = true;
double SSARJdiff = 0.00;
double oldSSARJstep = 0.00;
double oldSSARJangle = 0.00;
double oldSSARJ = 0.00;
double SSARJcheck = 0.00;
double SSARJstep = 0.00;

double B1B = 0.0;
double B2B = 0.0;
double B3B = 0.0;
double B4B = 0.0;
double B1A = 0.0;
double B2A = 0.0;
double B3A = 0.0;
double B4A = 0.0;
double PSARJ = -1.0;
double SSARJ = 0.0;
double PTRRJ = 0.0;
double STRRJ = 0.0;
boolean AOS = false;

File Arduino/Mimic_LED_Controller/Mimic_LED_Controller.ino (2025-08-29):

#include <FastLED.h>

// LED strip configuration
#define NUM_LEDS 48  // Total LEDs (24 per side)
#define DATA_PIN 5   // Port side
#define DATA_PIN2 6  // Starboard side

// Global brightness control (0-255)
uint8_t masterBrightness = 64;  // Start at 25% brightness to prevent brownout

// LED arrays
CRGB portLEDs[24];  // Port side
CRGB stbdLEDs[24];  // Starboard side

// LED group definitions - keep the same pixel mappings
int port_LEDs_4A[] = {0, 1, 2, 3, 4, 5};    // Port side, 4A array
int port_LEDs_2A[] = {6, 7, 8, 9, 10, 11};  // Port side, 2A array
int port_LEDs_4B[] = {12, 13, 14, 15, 16, 17}; // Port side, 4B array
int port_LEDs_2B[] = {18, 19, 20, 21, 22, 23}; // Port side, 2B array

int stbd_LEDs_3A[] = {0, 1, 2, 3, 4, 5};    // Starboard side, 3A array
int stbd_LEDs_1A[] = {6, 7, 8, 9, 10, 11};  // Starboard side, 1A array
int stbd_LEDs_3B[] = {12, 13, 14, 15, 16, 17}; // Starboard side, 3B array
int stbd_LEDs_1B[] = {18, 19, 20, 21, 22, 23}; // Starboard side, 1B array

// Color structure and lookup table
struct Color {
  const char* name;
  uint8_t r, g, b;
};

// Comprehensive color palette - easy to add new colors
const Color colorTable[] = {
  {"Red", 255, 0, 0},
  {"Green", 0, 255, 0}, 
  {"Blue", 0, 0, 255},
  {"White", 255, 255, 255},
  {"Yellow", 255, 255, 0},
  {"Magenta", 255, 0, 255},
  {"Cyan", 0, 255, 255},
  {"Orange", 255, 165, 0},
  {"Purple", 128, 0, 128},
  {"Pink", 255, 192, 203},
  {"Lime", 0, 255, 0},
  {"Teal", 0, 128, 128},
  {"Indigo", 75, 0, 130},
  {"Violet", 238, 130, 238},
  {"Gold", 255, 215, 0},
  {"Silver", 192, 192, 192},
  {"Brown", 165, 42, 42},
  {"Gray", 128, 128, 128},
  {"Off", 0, 0, 0},
  {"Black", 0, 0, 0}
};

const int NUM_COLORS = sizeof(colorTable) / sizeof(colorTable[0]);

// Animation and pattern states
boolean discoMode = false;
boolean pulseMode = false;
boolean chaseMode = false;
boolean rainbowMode = false;

// Animation timing (non-blocking)
unsigned long lastAnimationUpdate = 0;
unsigned long lastDiscoUpdate = 0;
unsigned long lastPulseUpdate = 0;
unsigned long lastChaseUpdate = 0;
unsigned long lastRainbowUpdate = 0;

// Animation parameters
int animationStep = 0;
int pulseBrightness = 0;
boolean pulseIncreasing = true;
int chasePosition = 0;
int rainbowHue = 0;

void setup() 
{
  Serial.begin(9600);
  Serial.setTimeout(50);
  
  // Initialize FastLED
  FastLED.addLeds<WS2812B, DATA_PIN, GRB>(portLEDs, 24);
  FastLED.addLeds<WS2812B, DATA_PIN2, GRB>(stbdLEDs, 24);
  
  // Set global brightness
  FastLED.setBrightness(masterBrightness);
  
  // Set all LEDs to off initially
  setAllLEDs("Off");
  
  // Test: turn on first LED of each side to verify hardware is working
  // Serial.println(F("Testing hardware - turning on first LED of each side"));
  portLEDs[0] = CRGB::Red;
  stbdLEDs[0] = CRGB::Blue;
  FastLED.show();
  delay(1000);
  
  // Turn them off
  portLEDs[0] = CRGB::Black;
  stbdLEDs[0] = CRGB::Black;
  FastLED.show();
  
  // Serial.println(F("Mimic LED Controller Ready (FastLED)"));
}

void loop() 
{
  // Check for serial commands (non-blocking)
  if (Serial.available()) 
  {
    char buffer[64];  // Increased buffer size
    int bufferIndex = 0;
    
    // Read all available characters
    while (Serial.available() && bufferIndex < 63) {
      char c = Serial.read();
      if (c == '\n' || c == '\r') {
        break;
      }
      buffer[bufferIndex++] = c;
    }
    
    buffer[bufferIndex] = '\0';
    
    if (bufferIndex == 0) return;
    
    // Debug: show what we received
    // Serial.print(F("Received: '"));
    // Serial.print(buffer);
    // Serial.println(F("'"));
    
    // Parse command
    if (strncmp(buffer, "LED_", 4) == 0) {
      // Serial.println(F("Processing LED command"));
      parseLEDCommand(buffer);
    } else if (strncmp(buffer, "PATTERN_", 8) == 0) {
      parsePatternCommand(buffer);
    } else if (strncmp(buffer, "ANIMATE_", 8) == 0) {
      parseAnimationCommand(buffer);
    } else if (strncmp(buffer, "BRIGHTNESS_", 11) == 0) {
      parseBrightnessCommand(buffer);
    } else if (strcmp(buffer, "DISCO") == 0) {
      discoMode = true;
      pulseMode = false;
      chaseMode = false;
      rainbowMode = false;
      // Serial.println(F("Disco mode ON"));
    } else if (strcmp(buffer, "RESET") == 0) {
      resetAllLEDs();
      // Serial.println(F("Reset complete"));
    } else if (strcmp(buffer, "STATUS") == 0) {
      printStatus();
    } else if (strcmp(buffer, "HELP") == 0) {
      printHelp();
    } else if (strcmp(buffer, "TEST") == 0) {
      // Serial.println(F("Running TEST command"));
      parseLEDCommand("LED_1A=Red");
    } else if (strcmp(buffer, "RED") == 0) {
      // Serial.println(F("Setting all LEDs to RED"));
      setAllLEDs("Red");
    } else if (strcmp(buffer, "OFF") == 0) {
      // Serial.println(F("Turning all LEDs OFF"));
      setAllLEDs("Off");
    }
    
    // Reset buffer
    bufferIndex = 0;
  }

  // Handle animations (non-blocking)
  unsigned long currentTime = millis();
  
  if (discoMode) {
    updateDiscoAnimation(currentTime);
  }
  
  if (pulseMode) {
    updatePulseAnimation(currentTime);
  }
  
  if (chaseMode) {
    updateChaseAnimation(currentTime);
  }
  
  if (rainbowMode) {
    updateRainbowAnimation(currentTime);
  }
  
  // Heartbeat every 10 seconds
  static unsigned long lastHeartbeat = 0;
  if (currentTime - lastHeartbeat > 10000) {
    lastHeartbeat = currentTime;
  }
}
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

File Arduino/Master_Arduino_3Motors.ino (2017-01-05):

// This version is built to turn 3 motors, PSARJ, BGA 2B & BGA 4B using the Driver Board Ports 1, 2, and 4 respectively.

// =========== Primary ToDo's ===========
// 1) Connect extra motors to ensure this version (3 motors) works
// 2) Change secondary encoder pin for each motor to be non-interrrupt pin
// 3) Debug all my errors....
//
// Eventually....
// 1) Set I2C address for 2nd and 3rd motor driver boards, as each board can drive only 4 motors.
//




#include <Adafruit_MotorShield.h>
#include "utility/Adafruit_MS_PWMServoDriver.h"
#include <string.h>

// Create the motor shield object with the default I2C address
Adafruit_MotorShield AFMS = Adafruit_MotorShield();
// Or, create it with a different I2C address (say for stacking)
// Adafruit_MotorShield AFMS = Adafruit_MotorShield(0x61);

// Select which 'port' M1, M2, M3 or M4. In this case, M1,2,4
Adafruit_DCMotor *myMotorPSARJ = AFMS.getMotor(1);
Adafruit_DCMotor *myMotorBeta2B = AFMS.getMotor(2);
Adafruit_DCMotor *myMotorBeta4B = AFMS.getMotor(4);


// pins for the encoder inputs
#include <Wire.h>

// Hardware interrupt pins on the Arduino Mega: 2, 3, 18, 19, 20, 21; 
// NOTE: Will eventually use only 1 interrupt pin per motor, which will support up to six motors.  Will try software interrupts for the rest, if possible.  Otherwise will need a second Ard, or one with more HW interrupts.

#define ENCODER_Beta2B_A 3  // Beta2B interrupt and 
#define ENCODER_Beta2B_B 2  // Beta2B encoder

#define ENCODER_Beta4B_A 18  // Beta4B interrupt and 
#define ENCODER_Beta4B_B 19  // Beta4B encoder

#define ENCODER_PSARJ_A 20  // PSARJ interrupt and 
#define ENCODER_PSARJ_B 21  // PSARJ encoder



void setup() {

  AFMS.begin(200);  // I sest this at 200 to reduce audible buzz.
  //AFMS.begin(1000);  // OR with a different frequency, say 1KHz

  pinMode(ENCODER_Beta2B_A, INPUT);
  pinMode(ENCODER_Beta2B_B, INPUT);
  pinMode(ENCODER_Beta4B_A, INPUT);
  pinMode(ENCODER_Beta4B_B, INPUT);
  pinMode(ENCODER_PSARJ_A, INPUT);
  pinMode(ENCODER_PSARJ_B, INPUT);

  // initialize hardware interrupts  NOTE: Per above, will eventually use non-interrupt pins for secondary Encoder counters (the "_B" ones)
  attachInterrupt(digitalPinToInterrupt(3), EncoderEvent_Beta2B, CHANGE);   // Beta2B
  attachInterrupt(digitalPinToInterrupt(18), EncoderEvent_Beta4B, CHANGE);   // Beta4B
  attachInterrupt(digitalPinToInterrupt(20), EncoderEvent_PSARJ, CHANGE);  // PSARJ

  Serial.begin(9600);
  Serial1.begin(115200);          //Serial1 is connected to the RasPi
  Serial1.setTimeout(50);

  Serial.println("Motor test!");

  // turn on motor   NOTE: May be able to remove all of these setSpeed and run commands here, although they are fine.
  myMotorBeta2B->setSpeed(150);
  myMotorBeta2B->run(RELEASE);

  myMotorBeta4B->setSpeed(150);
  myMotorBeta4B->run(RELEASE);

  myMotorPSARJ->setSpeed(150);
  myMotorPSARJ->run(RELEASE);

  // For debugging
  pinMode(13, OUTPUT); //LED
}

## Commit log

2023-09-07 Adding current Display Screenshots
2023-09-07 Updating current display screenshots for GUI Wiki
2023-10-02 Thickening slip ring attachment struts
    [HiFi_Truss_PS45.stl]
2023-10-05 Add files via upload
    Draft US Lab assembly and components in STEP as214
    [Aft Endcone.STEP, Cylinder.STEP, Fwd Endcone.STEP]
2023-10-05 Add files via upload
    US Lab draft assembly mesh
2023-10-31 Corrected file for 300 degrees motor (DS-S006L)
2023-11-09 Inserted space and label for apogee and perigee on orbit data screen
2023-11-09 Update GUI.py
    changing orbitMap schedule to every 30s from 10s so it has time to complete (not good solution - should track process id and make sure it closes before running again)
2023-11-20 Adding arduino count functionality to all screens
2023-11-28 Modify to accommodate motor
    [LoFi-ITS-S3-complex.stl]
2023-11-30 Updated Magnet File
    [ISS Mimic Magnet Mapping_113023.xlsx]
2023-11-30 New Magnet Polarity Map
2023-12-01 Adding remaining JEM EF files and splitting out bottom boxes for better printing
    [HiFi_JEM_Bottom_Box_x4.stl, HiFi_JEM_EF.stl, HiFi_JEM_EFU_Boxy.stl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]
2023-12-01 Adding clock and telmetry filtering functionality to webpage!
2023-12-02 Add files via upload
    P3 update for 4mm clearance hole for attached payloads, increased length of motor cavity, widened motor shaft holes. Closes #465.
    [LoFi_ITS-P3-complex.stl]
2023-12-02 Add files via upload
    S3 update for 4mm clearance hole for attached payloads, increased length of motor cavity, widened motor shaft holes.
    [LoFi_ITS-S3-complex.stl]
2023-12-03 Changing drop down menu to checkboxes
    Creating checkboxes on each telemetry row for filtering rather than scrolling the drop down menu
2023-12-03 Update index.html
    fixing off by one error in the filtering
2023-12-05 Adding new START/STOP buttons for playback screen
2023-12-05 Adding PLUS/MINUS buttons for Playback Screen
2023-12-07 Update Mimic_LED_Controller.ino
    Refactored Mimic LED Controller code
2023-12-09 Update Mimic_LED_Controller.ino
    might fix the issue with the current code
    [Mimic_LED_Controller.ino]
2023-12-09 Renaming fake orbit screen and adding LED statuses to output
2024-01-03 Updating VV bacground to current vehicle traffic
2024-01-03 Updating USOS background to current vehicle traffic
2024-01-21 This adds a .zip file in the Mini_Mimic Arduino folder to make it simpler for the teachers.
    This is not an ideal solution, but it makes it so the teachers will not have to individually download the 4 files into a folder. This change is from teacher feedback.
2024-01-21 Replace Mini Mimic files accidently deleted months ago
    Also updates the bundle .zip file
    [a_var_declarations.ino, b_Main_Loop.ino, z_interrupt_events.ino]
2024-02-20 Update ISS_Screen.kv
    Adding NRAL text label and button functionality
2024-02-20 Adding JLP text label and button functionality - moves JEM button and label down
2024-02-23 Update readme.md
    Linked the print-able corner bracket
2024-02-23 Rotated Mini TRRJ beam so it imports flat on print bed
    [0p5_Mimic_TRRJ-beam_rotated.stl]
2024-02-23 Rotated 0p5_Mimic_peg_RS-RSvv so that it comes in proper orientation
    Suggest using 0p5_Mimic_peg_RS-RSvv_rotated.stl and deleting non-rotated.
    [0p5_Mimic_peg_RS-RSvv_rotated.stl]
2024-02-23 Mini: Rotated JEMEF so the .stl imports in correct orientation
    Suggest keeping 0p5_Mimic_USOS_JEMEF_rotated.stl and deleting non-rotated
    [0p5_Mimic_USOS_JEMEF_rotated.stl]
2024-03-11 Added EXT and INT button code
2024-03-12 Adding EMU Sreen buttons and ne EMU screen background
2024-03-12 Adding EMU button to EMU Screen
2024-03-12 Left out Arduino Count code
2024-04-03 Changed Tracy's calculated starting count days in space from 188 to 189 - I had tried to account for hours but we do not track that
2024-07-24 Added Solid S0 Fusion Assembly
2024-07-24 S0 Solid Assembly first commit
2024-08-11 Rename LoFi_ITS-1_Mounts (1).stl to LoFi_ITS-1_Mounts.stl
    [LoFi_ITS-1_Mounts.stl]
2024-08-11 Arching LoFi stuff and other minor issue fixes
    [Cupola-Body.stl, Cupola-SideWindow.stl, Cupola-TopWindow.stl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]
2024-09-30 Fix #614 Update dashboard.html
    Special case handling for state vector radius X, Y, Z components took away the code path to actually updating the displayed text in the selector. Reinserted that code.
    Also fixed a typo in the ISS Time PUI (course --> coarse).
    Also removed the fine time PUI because it updates annoyingly frequently and chews up browser processor cycles.
2025-03-29 Update VVcheck.py - fix for date misalignments
    Adding some margin to the date correlations in case anything (NASA page) is wrong
2025-04-27 EduMimic Arduino code
    From 2024
2025-05-27 Update readme.md
    updated Mini BOM
2025-06-20 Move all crew over for Soyuz 72 guys landing (now Ep 73)
2025-08-04 disabling USB mount check for playback for now
2025-08-06 fixed sun, iss, working on groundtrack
2025-08-07 adding crew sleep timer
2025-08-07 tweaks to sleep timer
2025-08-08 AOS LOS timer update
2025-08-08 updating LOS AOS timers
2025-08-09 Refactor RS_Dock_Screen layout and error handling. Added dynamic font sizing and improved button background handling. Enhanced docking bar width update with exception logging for better debugging.
2025-08-10 removing prints
2025-08-11 changing eva timer logic
2025-08-11 debug button pos
2025-08-12 LED test functionality and refactor
2025-08-12 trying to add fix led screen and controller
    [Mimic_LED_Controller.ino]
2025-08-12 led screen fix maybe
2025-08-12 adding functions to led
2025-08-12 Removed a lot of TX from arduino clogging up the pipeline
2025-08-12 tweaking LED screen
2025-08-16 Update GUI.py for more current launch day calculations
2025-08-17 removed redudant arduino status
2025-08-17 arduino count fix
2025-08-17 adding new playback file and loop button functionality
2025-08-17 adding debug prints
2025-08-17 removing print
2025-08-18 adding LED logic and data files, removing old data files
2025-08-18 fixing LED logic
2025-08-18 led logic fix
2025-08-18 breaking out LED commands into separate serialWrite
2025-08-18 changing led controller and reverting LED command
    [Mimic_LED_Controller.ino]
2025-08-18 fix calibrate zero button
2025-08-19 adding popup info button
2025-08-20 change disco LED command
2025-08-20 adding LED reset to stop button
2025-08-20 tweak to disco led command
2025-08-20 adding current disco json
2025-08-20 adding arduino status updates
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2025-08-22 trying out splitting up LED commands again (didnt work last time)
2025-08-24 disable buttons when no Ards, add transmit animations
2025-08-24 fixing arduino detection
2025-08-24 scaling on led screen
2025-08-24 led arduino transmit animation
2025-08-24 disabling LED buttons if no arduinos
2025-08-24 reverting LED screen, adding test disable button
2025-08-24 disabling buttons if no arduinos
2025-08-25 fix LED command
2025-08-25 adding arduino transmit functionality to base class
2025-08-25 handing off arduino stuff back to GUI
2025-08-26 debug prints for arduino transmit
2025-08-26 tweak buttons on mimic screen
2025-08-26 removing debug prints adding status updates
2025-08-26 fixes to LED commands and EPS tweaks
2025-08-26 splitting out LED commands
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2025-08-29 separating out LED commands from playback
2025-08-29 combining LED command into one so motors dont freak out
2025-08-29 combining back into two separate port and stbd LED commands

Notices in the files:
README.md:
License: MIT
